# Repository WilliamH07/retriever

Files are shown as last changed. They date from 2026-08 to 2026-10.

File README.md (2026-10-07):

<div align="center">

# Retriever

**Open source autonomous outdoor mobile robot**






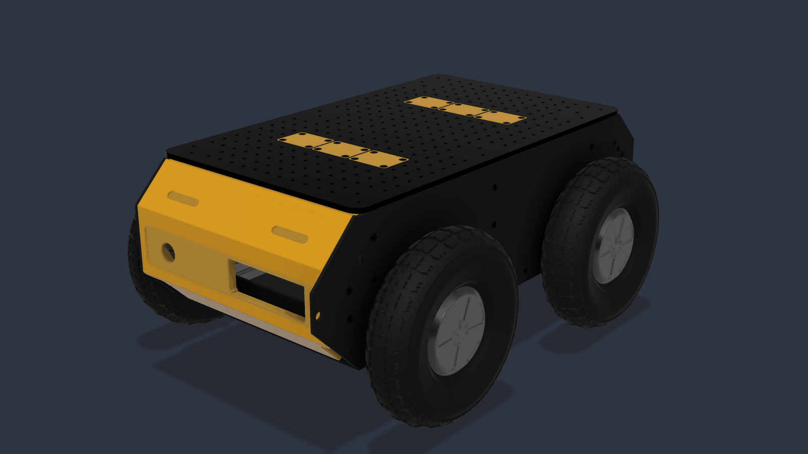
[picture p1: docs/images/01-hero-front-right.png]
Retriever


</div>

---

## What this is

Retriever is a four wheel drive outdoor mobile robot, built independently and
released as open hardware. Its single objective is autonomous outdoor
navigation using ROS 2 Jazzy and the Nav2 stack, on a chassis that anyone can
reproduce from documented, commodity parts.

The project is an open rebuild inspired by the [Clearpath
Husky](https://clearpathrobotics.com/husky-a300-unmanned-ground-vehicle-robot/),
a research platform that has become a reference in mobile robotics
laboratories. The Husky is an excellent machine and a commercial product priced
accordingly. Retriever asks a different question: how much of that capability
can be reached by one person, from recovered and off the shelf components, if
the engineering is done properly rather than cheaply?

What makes the project unusual is not the hardware, which is deliberately
ordinary. It is the discipline applied to it: a complete architecture dossier
written before the first part was cut, a documented failure mode analysis, a
hardware safety chain that no software can override, and a build plan with a
measurable exit criterion at every stage.

## Status

| Stage | Exit criterion | State |
|:-----:|---|---|
| 1 | Architecture and CAD design complete | done |
| 2 | Chassis fabricated and assembled | **current** |
| 2b | First sensor published to ROS 2 over a transport-agnostic link | **current** |
| 3 | Power chain energised, no motor connected | next |
| 4 | Motors driven, wheels raised, all stop tests pass | planned |
| 5 | Autonomous outdoor navigation to a waypoint | planned |

Beyond stage 5, the intention is to mount a [Niryo
One](https://github.com/NiryoRobotics/niryo_one) arm on Retriever and turn the
platform into a mobile manipulator.

<div align="center">
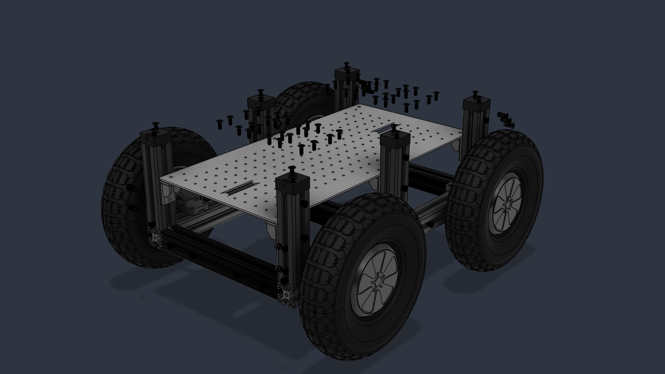
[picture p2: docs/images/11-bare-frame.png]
Aluminium extrusion frame

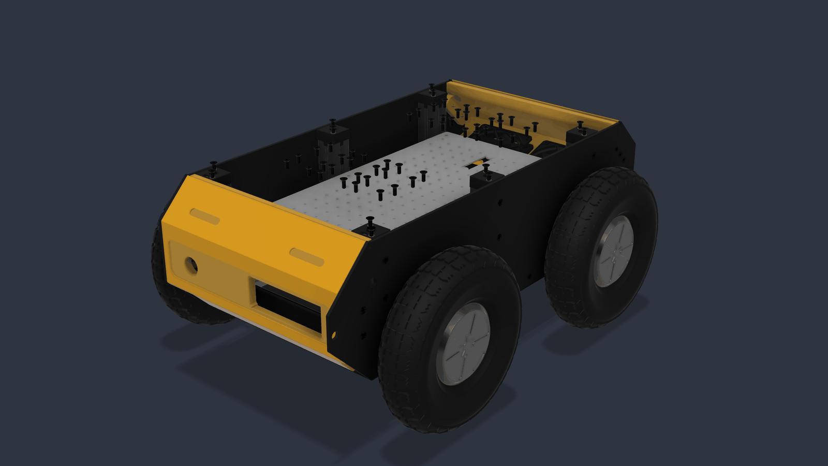
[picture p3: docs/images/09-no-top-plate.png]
Both decks visible

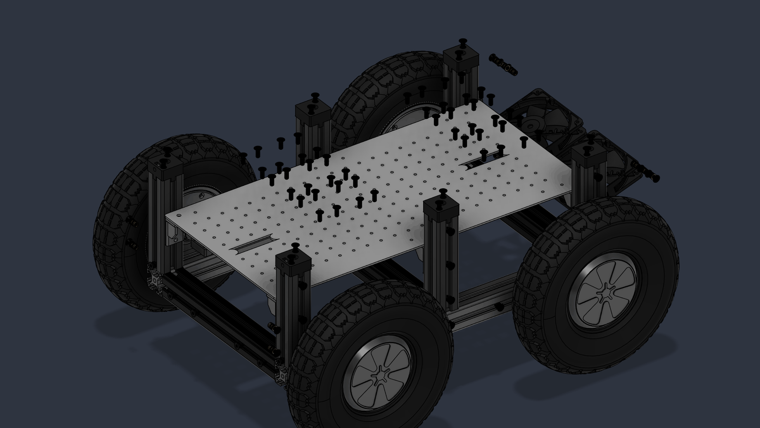
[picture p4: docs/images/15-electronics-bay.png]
Electronics bay

</div>

### The same thing, built

<div align="center">
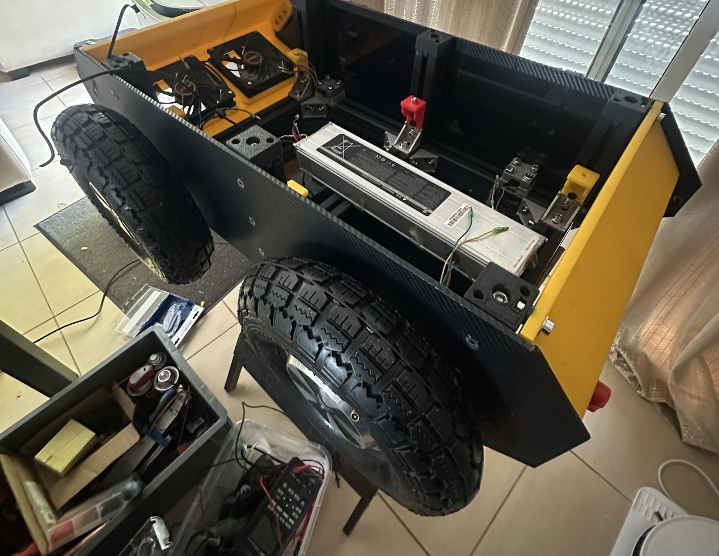
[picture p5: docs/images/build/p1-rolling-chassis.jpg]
Frame with battery and cooling fitted

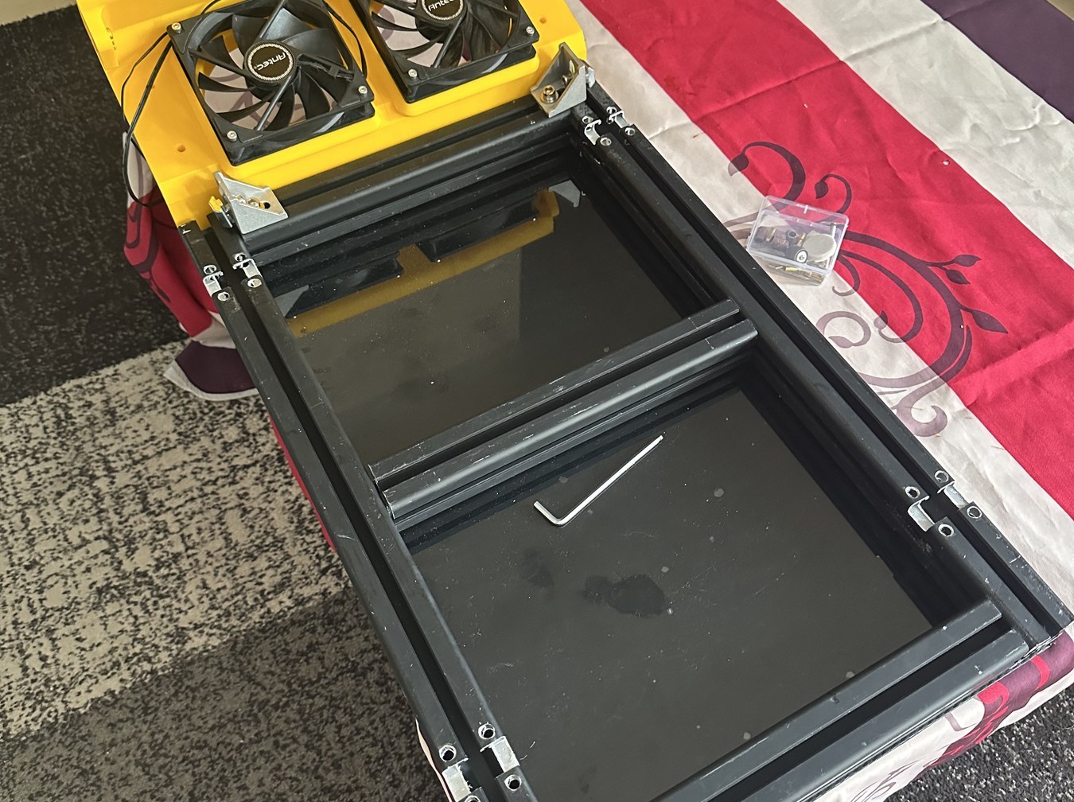
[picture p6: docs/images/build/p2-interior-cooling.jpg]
Twin fans over the electronics bay

</div>

## Three design decisions

**A CAN bus, not USB, carries every command.** Four BLDC controllers chopping
tens of amps within 30 cm of the signal wiring make USB the wrong choice for
the control path: it is a master slave bus, dynamically enumerated, with no
frame priority. CAN 2.0A at 500 kbit/s links the computer to every
microcontroller instead. USB is retained only for high bandwidth perception
sensors, whose loss degrades the mission but cannot cause dangerous motion.

**The main computer never does real time.** It runs perception, localisation,
Nav2 and the mission state machine, and it produces setpoints. A dedicated
safety microcontroller decides whether those setpoints may be executed. The
computer requests arming; the safety controller grants or refuses it. A ROS 2
bug, an out of memory kill or a blocked kernel cannot produce movement.

**Safety is hardware, and independent of software.** Six stop levels, from a
100 ms software collision monitor down to a mechanically latching emergency
stop wired in series with the main DC contactor coil. The last two levels
contain no code at all.

```
N1  ROS 2 collision monitor and cmd_vel timeout        ~100 ms
N2  ros2_control SystemInterface returns ERROR          ~50 ms
N3  ESP32 MOTION, no CAN frame for 150 ms, setpoint 0  ~150 ms
N4  ESP32 SAFETY, overcurrent or lost heartbeat         ~20 ms
N5  HARDWARE LOOP, latching emergency stop              ~10 ms
N6  Manual battery isolator and main fuse
        Only N5 and N6 are independent of all software
```

## Hardware at a glance

| | |
|---|---|
| Configuration | 4WD skid steer, outdoor |
| Structure | Aluminium extrusion frame, laser cut panels, 3D printed mounts |
| Target mass | 35 kg in running order |
| Target speed | 1.5 m/s |
| Drivetrain | 4 x 6.5 inch hub motors, 250 W each |
| Motor drivers | 4 x BLDC controllers, 36 to 48 V |
| Battery | 36 V, 280 Wh lithium ion, 10S3P |
| Endurance | 70 min at 200 W average |
| Compute | x86 SBC, Ubuntu 24.04, ROS 2 Jazzy |
| Real time | 3 x ESP32 on CAN 2.0A, 500 kbit/s |
| Localisation | GNSS, IMU and wheel odometry, dual EKF |
| Navigation | Nav2, collision monitor, twist mux |

## Repository layout

```
docs/
  architecture/     the eight document architecture dossier
  measurements/     results of the bench measurements M1 to M12
  images/           photos and renders
  sponsorship/      the sponsorship dossier
hardware/
  cad/              mechanical design, STEP and STL
  pcb/              board designs, EasyEDA sources and gerbers
  bom/              costed bill of materials
firmware/
  esp32_motion/     motor control loop, 200 Hz
  esp32_safety/     safety state machine, watchdogs, contactor
  protocol/         protocol.yaml and the code generator
ros2_ws/src/
  retriever_bringup/       launch files and system configuration
  retriever_description/   URDF, meshes, physical parameters
  retriever_msgs/          message definitions
  retriever_hardware/      ros2_control SystemInterface over SocketCAN
  retriever_control/       controller configuration
  retriever_navigation/    Nav2 and robot_localization configuration
  retriever_teleop/        manual control and the operator console
```

## Documentation

**Where the work stands:** [HANDOFF — IMU](docs/HANDOFF-banc-imu.md) and
[HANDOFF — lidar](docs/HANDOFF-banc-lidar.md) — what runs today with measured
numbers, the silent defects found and how each one worked, and what is left to
do once the sensors are mounted. In French.

**Start here:** [Démarrage](docs/DEMARRAGE.md) — what to install, how to flash
the ESP32, how to build the ROS 2 workspace, and how to verify the IMU chain at
every stage, with the traps that have already cost a day each. In French.

The architecture dossier was written before construction began. It is in
French; an English summary is planned.

| Document | Contents |
|---|---|
| [00 Index](docs/architecture/00-index-A-B.md) | Summary, assumptions, open questions |
| [01 Electrical](docs/architecture/01-inventaire-electrique.md) | Inventory, power architecture, busbars |
| [02 Comms](docs/architecture/02-comms-esp32-moteurs.md) | CAN bus, ESP32 roles, motors |
| [03 ROS 2](docs/architecture/03-ros2-etats-boot.md) | Node graph, state machine, boot |
| [04 Safety](docs/architecture/04-securite-watchdogs-capteurs.md) | Stop chain, watchdogs, sensors |
| [05 Software](docs/architecture/05-reseau-code-tests-physique.md) | Network, code layout, test strategy |
| [06 BOM](docs/architecture/06-bom-fmea-schema-plan.md) | Bill of materials, FMEA, build plan |
| [07 Operator](docs/architecture/07-interface-operateur.md) | Operator console |
| [13 Software](docs/architecture/13-architecture-logicielle-liaison.md) | Link layer, firmware, ROS 2 chain, IMU bench |

Every claim in these documents carries a marker: verified against a datasheet,
community consensus, to be measured, or an explicit assumption. Nothing gets
wired before the measurements it depends on have been made.

## Supporting the project

Retriever is self funded by a student. Three items stand between the current
platform and autonomous outdoor operation:

- **Printed circuit boards.** Three boards are being designed in EasyEDA: a
  motor driver interface, a safety and power management board, and a CAN
  distribution board.
- **Embedded AI compute.** The current x86 board runs the navigation stack, but
  not the perception outdoor autonomy asks for.
- **An outdoor LiDAR.** The blocking item. The 2D LiDAR on hand is specified for
  indoor use, and direct sunlight saturates its receiver.
- **A depth camera.** The Kinect v2 on hand is blind in daylight and its driver
  has been unmaintained since 2021.

Sponsors get a written and filmed integration tutorial for the sponsored part,
a field test video with honest performance data, attribution on the chassis and
here in this README, and private feedback on how the part behaves on a real
robot before anything is published.

The full sponsorship dossier is in [docs/sponsorship](docs/sponsorship/).
Enquiries welcome: see contact below.

## Credits

Inspired by the Clearpath Husky platform. The mechanical design was modelled
from scratch and the electrical and software architecture designed
independently. Some ROS 2 package conventions follow the open source
[husky/husky](https://github.com/husky/husky) repository, which is published
under BSD 3 Clause. Clearpath Robotics is not affiliated with this project and
does not endorse it.

See [CREDITS.md](CREDITS.md) for the full attribution.

## Licence

Software and firmware are released under the [Apache License 2.0](LICENSE).
Hardware designs, CAD and PCB files are released under the [CERN Open Hardware
Licence Version 2, Strongly Reciprocal](LICENSE-HARDWARE.txt).

## Contact

William Hanczyk, Bordeaux, France
wcontact33@gmail.com

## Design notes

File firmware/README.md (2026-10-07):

# Firmware

Three ESP32 nodes in the target architecture. The IMU bench runs on
`esp32_safety`; the motor bench now has front, rear and single-ESP profiles.
Setup and commissioning: [`esp32_motion/README.md`](esp32_motion/README.md).

| Node | Role | State |
|---|---|---|
| `esp32_safety/` | Safety state machine, current budget, watchdogs, precharge, contactor, BMS telemetry, and the BNO085 IMU. | **IMU chain only.** No safety function is implemented, and none can be validated on the serial bench. |
| `esp32_motion/` | Front/rear units, or one bench unit controlling up to four ZS-X11H drivers. | PWM/RC bench, software self-test, gated arming, watchdog and telemetry. Hall feedback and final PCB DAC/safety drivers remain to implement. |

## Layout

```
protocol/      protocol.yaml — the single source of truth — and its generator
components/    shared between every node
  retriever_protocol/   the generated header
  retriever_link/       transport-agnostic link layer
    portable/           C99, no ESP-IDF: compiled by the firmware AND by ROS 2
  retriever_imu/        BNO085 behind a four-function interface
esp32_safety/  the IMU ESP-IDF project
esp32_motion/  common front/rear/four-wheel ESP-IDF project
test/          host tests — no hardware, no ESP-IDF, no ROS
```

## The one idea worth knowing

Application code only ever sees `rt_frame_t`: an 11 bit identifier and at most
eight bytes. It does not know whether those frames travel over a CAN bus or a
USB cable. Today they travel over serial, because the CAN distribution board
does not exist yet. When it does, one Kconfig option switches the firmware and
one launch parameter switches the computer. Both CAN backends are already
written — `link_twai.c` and `socketcan_transport.cpp` — and their size is the
measure of whether the abstraction sits in the right place.

⚠️ Serial gives no arbitration, no acknowledgement, no retransmission and no
fault confinement. **No safety function is validated on it**, and stop levels
N4 and N5 stay in hardware where they belong. Section AB.5 of the architecture
document is the full list.

## Build

Full setup — toolchain, drivers, port, and how to check the result — is in
[`docs/DEMARRAGE.md`](../docs/DEMARRAGE.md). The short version:

```bash
git submodule update --init --recursive     # or tools/fetch_firmware_deps.sh
cd firmware/esp32_safety
idf.py set-target esp32
idf.py build flash
```

ESP-IDF v5.5. The SH-2 sensor hub stack is CEVA's, Apache 2.0, pinned as a
submodule and never modified; what belongs to this project is the port,
`sh2_hal_esp32_spi.c`.

## Host tests

```bash
make -C firmware/test          # protocol and framing, no hardware needed
python3 tools/check_protocol_sync.py
```

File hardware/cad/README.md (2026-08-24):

# Mechanical design

Aluminium extrusion frame, laser cut panels, 3D printed mounts. The design is
complete and the parts are made; this folder holds the files they were made
from.

```
dxf/        laser cutting profiles, one file per flat part
stl/        printable parts, ready to slice
step/       STEP exports, for anyone using a different CAD tool
source/     native CAD files
```

## Laser cut panels

Six flat parts make up the body and the decks. All are cut from sheet, and all
are in `dxf/`.

| File | Part | Material |
|---|---|---|
| `ETG_Plateau_superieur_PMMA_3mm.dxf` | Upper deck | PMMA, 3 mm |
| `Plancher.dxf` | Floor of the payload bay | |
| `Panneau_AVANT.dxf` | Front panel | |
| `Panneau_ARRIERE.dxf` | Rear panel | |
| `Panneau_lateral_DROIT.dxf` | Right side panel and wheel arch | |
| `Panneau_lateral_GAUCHE.dxf` | Left side panel and wheel arch | |

The side panels carry the wheel arches, so their outline is what sets the
wheelbase and the track. Change one and the URDF in
[`ros2_ws/src/retriever_description`](../../ros2_ws/src/retriever_description)
has to follow.

Material and thickness are recorded in the file name where they matter. Fill in
the blanks in the table above as each part is confirmed.

## Printed parts

The corner brackets, the deck brackets, the wheel mounts, the fan housing and
the front section are printed. STL files go in `stl/`.

For each part, note here the material, the layer height, the wall count and
the infill actually used, not the ones intended. A printed bracket that holds a
35 kg machine is a structural part, and the print settings are part of the
specification.

## Frame

The frame is aluminium extrusion, cut and drilled by hand. Lengths and the
drilling pattern belong in `source/`, with the extrusion profile and the corner
connector reference recorded here once confirmed.

## Renders

The renders in [`docs/images`](../../docs/images) are produced from this model
by a Fusion 360 script that fixes the camera, the visual style and the
visibility of each assembly group. A regenerated set is directly comparable to
the current one.

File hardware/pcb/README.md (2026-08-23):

# Printed circuit boards

Three boards, currently being designed in EasyEDA.

| Board | Function | State |
|---|---|---|
| [`motor_interface/`](motor_interface/) | Hall passthrough with wire colour remapping, level shifting and signal conditioning to the pulse counters, CAN breakout | routed, pre production review |
| [`safety_power/`](safety_power/) | Power distribution, 37 V / 12 V / 5 V buses, fusing, overvoltage and regeneration protection, precharge, current sensing | specified |
| `can_distribution/` | CAN bus distribution with termination, node breakout and supply fan out | in design |

Each board folder should end up containing:

```
schematic.pdf        human readable schematic
gerbers/             fabrication output
bom.csv              bill of materials
pick_and_place.csv   if assembled
README.md            what it does, connectors, test points
```

Source files are exported from EasyEDA. Fabrication output is committed so that
anyone can order the boards without opening a design tool.

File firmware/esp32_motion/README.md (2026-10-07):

# MOTION — banc avant, arrière ou quatre roues

Un même projet ESP-IDF v5.5 produit les programmes des deux ESP32 classiques
DevKitC/WROOM et celui du banc à un seul ESP32. Les variateurs ZS-X11H assurent
la commutation BLDC ; l'ESP32 leur fournit VR, DIR et STOP. Le firmware ne
commute pas directement les phases du moteur.

Les cartes `motor_interface` étant encore en conception, ces profils pilotent
**le montage de banc PWM + RC**. Ils ne pilotent pas encore le MCP4728, les
Hall, l'ADS1115, `/SAFE`, le frein EL ou le watchdog externe de la carte finale.

## Profils et câblage

| Profil | Identité | Roues globales | Sorties locales | Masque pour armer |
|---|---|---|---|---|
| `front` | MOTION_FRONT, 2 | m0 avant gauche, m1 avant droite | 0, 1 | 3 |
| `rear` | MOTION_REAR, 3 | m2 arrière gauche, m3 arrière droite | 0, 1 | 12 |
| `bench4`, 3 moteurs | MOTION_FRONT, 2 | m0, m1, m2 | 0, 1, 2 | 7 |
| `bench4`, 4 moteurs | MOTION_FRONT, 2 | m0, m1, m2, m3 | 0, 1, 2, 3 | 15 |

Le banc utilise l'identité FRONT : ne pas connecter simultanément un banc4 et
un FRONT sur le même CAN. Les cartes avant et arrière utilisent les **mêmes
broches locales**, mais sélectionnent des indices de roues différents.

| Sortie locale | PWM → VR | DIR | STOP |
|---|---|---|---|
| 0 | GPIO25 | GPIO26 | GPIO27 |
| 1 | GPIO32 | GPIO33 | GPIO14 |
| 2, banc seulement | GPIO18 | GPIO19 | GPIO21 |
| 3, banc seulement | GPIO22 | GPIO23 | GPIO13 |

UART USB : GPIO1/3, 921600 bauds. CAN : TX GPIO5, RX GPIO4, 500 kbit/s,
transceiver externe obligatoire. Deux terminaisons de 120 Ω aux extrémités.
GPIO5 est une broche de strapping : vérifier son état haut au démarrage.

**Interface DIR/STOP obligatoire.** Le drain ouvert interne ne rend pas les
GPIO tolérants au 5 V. Le rappel du variateur ne doit jamais arriver directement
sur l'ESP32. Voir les limites électriques de la
[datasheet Espressif](https://documentation.espressif.com/esp32_datasheet_en.html).

Deux configurations logicielles sont prévues ; choisir celle qui correspond au
montage effectivement réalisé et mesurer les niveaux avant connexion :

- Par défaut, interface externe **non inversante**, côté ESP limité à 3,3 V,
  GPIO en drain ouvert. STOP logique 0 doit donner STOP variateur bas.
- `--inverted` : un NMOS externe par ligne, source à GND, drain à DIR ou STOP,
  grille au GPIO. Le GPIO est en push-pull 3,3 V ; niveau GPIO haut donne
  niveau variateur bas. Tirer la grille du NMOS STOP à 3,3 V par 10 kΩ pour
  maintenir STOP bas pendant le reset tant que ce rail est alimenté.

Le RC de banc est GPIO PWM → 1 kΩ → VR, avec 2,2 µF vers GND sur VR et un
rappel 10 kΩ vers GND **côté variateur**. Pleine échelle électrique environ
3 V, à vérifier sous charge ; elle ne représente pas une vitesse étalonnée.
Les masses de l'ESP et des interfaces sont communes. EL n'est pas piloté.
Le comportement en absence d'alimentation logique reste à vérifier matériellement.

## Compiler et téléverser

Sur le Mac, ESP-IDF v5.5 est installé dans `~/esp/esp-idf-v5.5`. Le raccourci
`get_idf`, disponible dans un nouveau terminal, active son environnement.
Installation selon la [notice officielle Espressif](https://docs.espressif.com/projects/esp-idf/en/v5.5/esp32/get-started/linux-macos-setup.html).
Le script Mac l'active automatiquement ; depuis la racine du dépôt :

```bash
./tools/flash_motion_mac.sh bench4 --count 4
./tools/flash_motion_mac.sh bench4 --count 4 --flash --port <port-USB>
```

La première commande compile seulement ; la seconde téléverse. `--count`
configure les premiers emplacements ; il ne détecte pas les roues présentes.
Les profils `front`,
`rear`, `--inverted` et `--transport can` fonctionnent aussi avec ce raccourci.

Depuis la racine du dépôt, après chargement de l'environnement ESP-IDF :

```bash
. <installation-esp-idf-v5.5>/export.sh
python3 tools/flash_motion.py front
python3 tools/flash_motion.py rear
python3 tools/flash_motion.py bench4 --count 3
```

Chaque profil, transport, nombre de sorties et type d'interface a son propre
répertoire sous `firmware/esp32_motion/build/`. Le programme régénère son
`sdkconfig` depuis les valeurs versionnées à chaque exécution : pas de rôle
avant conservé par erreur dans une compilation arrière, ni d'ancien défaut
masquant une modification du watchdog. Pour modifier un réglage permanent,
modifier les defaults versionnés ; les changements manuels de ce `sdkconfig`
généré sont écrasés.

Identifier physiquement les deux ports avant de flasher, puis :

```bash
python3 tools/flash_motion.py front --flash --port <port-ESP-avant>
python3 tools/flash_motion.py rear --flash --port <port-ESP-arriere>
```

Ajouter `--inverted` pour les NMOS externes inversants. Ajouter `--transport can`
quand les transceivers sont câblés. Pour une seule roue sur un essieu, utiliser
`--count 1` : elle occupe le **premier** emplacement local (m0 ou m2). Pour
une roue droite seule, déplacer provisoirement son câblage sur cet emplacement
et consigner l'écart dans le relevé du banc.

Avec l'avant droit déconnecté, conserver `--count 4` et les indices fixes.
Les roues présentes sont m0, m2, m3 : masque 13 (1 + 4 + 8). Pour les premiers
essais, autoriser séparément 1, 4 et 8 ; garder m1 à zéro. `--count 3` serait
adapté à un câblage regroupé sur les sorties 0, 1, 2, qui est un autre montage.
Après remontage de la quatrième roue : masque 15.

**Protocole 0.2.0.** Reconstruire le workspace ROS et reflasher le nœud IMU
quand il est utilisé avec ce workspace : le hash est commun à tout le dépôt.
Les captures anciennes restent décodables, mais l'ancien outil de commande
ne valide pas MOTOR_SESSION et ne peut plus armer ce firmware.

## Self-test et diagnostics

Le firmware initialise toutes les sorties à l'arrêt et interdit les moteurs.
Avant cette initialisation, pendant le reset, leur état dépend des rappels et
de l'interface électrique du banc.

| Bit | Contrôle réellement effectué |
|---|---|
| CONFIG, 0x01 | Indices, GPIO valides et distincts, réservations flash/console/CAN, limites finies |
| GPIO, 0x02 | Configuration DIR/STOP, écriture puis lecture des niveaux GPIO de repos |
| PWM, 0x04 | Initialisation LEDC, fréquence 20 kHz et lecture de chaque duty à zéro |
| TASK, 0x08 | Création de la tâche 200 Hz et inscription au task watchdog ESP-IDF |
| LINK, 0x10 | Initialisation du transport, files et tâches de liaison |

Attendu : `passed=31` (0x1F), `failed=0`, `output_errors=0`. Un défaut de
périphérique inhibe l'armement jusqu'au redémarrage. Le watchdog de tâche est
réglé à 2 s avec panic/reset ; il ne remplace pas le watchdog matériel externe.

Ces contrôles vérifient les périphériques et le logiciel. Ils ne prouvent pas
la tension VR au connecteur, la présence du variateur, le mouvement, le sens
mécanique ou le freinage. `configured_mask` décrit la configuration compilée,
**pas une détection automatique de la roue manquante**. Les contrôles physiques
restent dans la recette ci-dessous.

Les états, diagnostics et heartbeats sont publiés à 10 Hz :

| | Avant ou banc4 | Arrière |
|---|---|---|
| Consignes appliquées | MOTOR_STATE, 0x1A0 | MOTOR_STATE_REAR, 0x1A1 |
| Self-test / compteurs | MOTOR_DIAG_FRONT, 0x1A2 | MOTOR_DIAG_REAR, 0x1A3 |
| État / uptime / hash | HEARTBEAT_MOTION_FRONT, 0x702 | HEARTBEAT_MOTION_REAR, 0x703 |

Les quatre valeurs sont toujours ordonnées m0, m1, m2, m3. Les positions non
locales restent nulles. L'état renvoie une consigne électrique après limites,
pente et autorisations ; **il ne renvoie aucune vitesse mesurée**. Les erreurs
de sortie rendent cette consigne non fiable : lire `OUTPUT_FAULT` et le compteur.

READY signifie logiciel initialisé, sorties interdites. ACTIVE signifie
armement accepté, y compris à consigne zéro. DEGRADED signale un arrêt logiciel
ou une perte de commandes après armement. FAULT signale un self-test ou une
sortie en échec. `PROTOCOL_BLOCKED` précise qu'aucune session concordante n'a
encore été reçue, même si les périphériques sont prêts.

Sur CAN, les journaux restent sur la console locale : le LOG commun du banc
série n'est pas utilisé par deux émetteurs concurrents. Les diagnostics gardent
leurs identifiants distincts. LINK_PONG est une réponse à une cible explicite.

## Armement et comportement en défaut

L'ordinateur valide le hash reçu puis envoie MOTOR_SESSION avec l'identité
cible et le même hash. Le firmware vérifie aussi ce hash. Ensuite :

1. Envoyer une MOTOR_CMD à zéro, répétée à 50 Hz.
2. Attendre une télémétrie fraîche avec sorties nulles et self-test réussi.
3. Envoyer MOTOR_ENABLE avec magic 0xEB et le masque voulu.
4. Attendre le masque confirmé, puis envoyer les consignes à 50 Hz.

Le firmware rejette les DLC incorrects, les gardes incorrectes, les masques
hors b0..b3 et les consignes hors [-1,1]. Une commande invalide ne rafraîchit
pas le watchdog. Les roues de l'autre essieu sont filtrées.

Défauts et réglages du banc :

- Plus de 500 ms sans commande valide : consignes nulles, STOP bas et
  **désarmement mémorisé**. Le retour de liaison ne réarme jamais.
- Arrêt logiciel : consignes nulles et désarmement, réarmement explicite à zéro.
- Défaut de sortie : tentative de STOP/PWM zéro sur toutes les sorties,
  défaut mémorisé, redémarrage requis.
- Bus-off observé : arrêt logiciel mémorisé, même après reprise automatique du CAN.
- Limite de duty par défaut : 0,25. Une demande supérieure est limitée et
  `LIMITED` est publié. Ce n'est ni 25 % d'une vitesse mesurée ni une limite de courant.
- Accélération : 2 unités/s. Réduction et coupure sans rampe logicielle ; le RC
  et la mécanique ont leur propre délai.
- Inversion : passage à zéro, DIR conservé et pause de 250 ms avant inversion.
  **Cette pause ne démontre pas que la roue est arrêtée.** Sans Hall, attendre
  l'immobilisation mécanique avant de demander l'autre sens.

Le traitement logiciel se fait au prochain cycle de 5 ms sous ordonnancement
normal. STOP donne la roue libre, pas un freinage garanti. Les essais se font
roues levées, avec une coupure de puissance accessible. La chaîne matérielle
`/SAFE` / EL / contacteur reste à réaliser et à valider sur les cartes.

## Vérifier sans ROS

Dépendances : `pyyaml`, `pyserial` ; pour SocketCAN sous Linux, `python-can`.

```bash
python3 tools/motor_bench.py --device <port-avant> --self-test --report <resultat-avant.json>
python3 tools/motor_bench.py --device <port-arriere> --node rear --self-test --report <resultat-arriere.json>
```

`--self-test` observe sans envoyer de commande ou d'armement et retourne un
code non nul si la télémétrie est absente, périmée, incohérente, en erreur ou
si les sorties sont actives. Par défaut, l'outil **ne demande plus de reset**
à l'ouverture USB (`--no-reset` reste accepté). `--reset` demande explicitement
un redémarrage : l'utiliser uniquement puissance moteur coupée. Le circuit
USB-série et son pilote peuvent encore produire des transitions à l'ouverture ;
les rappels matériels restent nécessaires pendant un reset ou une coupure USB.

L'acquisition de la télémétrie est limitée à trois secondes, puis l'outil
observe pendant la durée `--seconds`. Les octets du bootloader, émis à une
autre vitesse sur UART0, restent visibles dans `decoder_acquisition`.
`decoder_observation` compte la période synchronisée : toute erreur de CRC,
format ou débordement pendant cette période fait échouer le test. Le verdict
global est `exit_code: 0`, pas seulement `healthy: true`.

`healthy` décrit la fraîcheur de la télémétrie et le self-test. Il ne signifie
pas que l'armement est autorisé. `session_ready` exige en plus la confirmation
de MOTOR_SESSION et d'une commande fraîche dans les deux retours STATE et
DIAG. Avant l'armement, le script répète uniquement SESSION et les commandes
zéro jusqu'à cette confirmation. Les premiers paquets perdus pendant le boot
ne doivent pas conduire à une tentative d'armement prématurée. Le firmware
attend aussi l'installation du traitement des commandes avant sa première
publication d'état.

Sur le Mac, avant ROS, depuis la racine du dépôt :

```bash
source ~/esp/esp-idf-v5.5/export.sh
python3 tools/motor_bench.py --device /dev/cu.usbserial-0001 --self-test --seconds 10 --report firmware/esp32_motion/build/mac-self-test.json
python3 tools/motor_bench.py --device /dev/cu.usbserial-0001 --enable 0 --duty 0 0 0 0 --seconds 3 --report firmware/esp32_motion/build/mac-zero-test.json
```

Remplacer le port si nécessaire. La seconde commande vérifie les commandes
zéro et le retour de désarmement sans autoriser une roue. Attendre
`exit_code: 0` et `shutdown_confirmed: true`. Ensuite seulement, roues levées
et interface électrique vérifiée, essayer une roue à la fois :

```bash
python3 tools/motor_bench.py --device /dev/cu.usbserial-0001 --enable 1 --duty .1 0 0 0 --seconds 3
python3 tools/motor_bench.py --device /dev/cu.usbserial-0001 --enable 4 --duty 0 0 .1 0 --seconds 3
python3 tools/motor_bench.py --device /dev/cu.usbserial-0001 --enable 8 --duty 0 0 0 .1 --seconds 3
```

Ces trois essais laissent l'avant droit (m1) interdit. Vérifier le mouvement
physique, le sens et l'arrêt ; les retours actuels ne mesurent pas la rotation.

### Diagnostic de sélection des sorties

Les quatre canaux LEDC sont indépendants et partagent uniquement le timer
de fréquence. Une seule tâche effectue les écritures. À chaque cycle de 5 ms,
le firmware relit les rapports cycliques LEDC du cycle précédent et les pads
STOP. Un écart avec les écritures attendues déclenche un défaut mémorisé et
l'arrêt de toutes les sorties. Les sorties inactives sont réécrites à zéro
avant la mise à jour des sorties actives.

`applied_m0..m3` est maintenant calculé depuis les registres PWM relus, avec
le signe de la commande écrite. Ce retour peut avoir un cycle de retard et
ne vérifie ni la tension VR après l'interface, ni la rotation. Le masque
`stop_gpio_high` est celui des niveaux physiques côté ESP, avant l'interface ;
sa polarité dépend donc de `--inverted`.

Après téléversement de cette version, exemple de relevé pour m3 seul :

```bash
python3 tools/motor_bench.py --device /dev/cu.usbserial-0001 --enable 8 --duty 0 0 0 .1 --seconds 3 --logs --report firmware/esp32_motion/build/m3-diagnostic.json
```

Le journal doit contenir `readback pwm=[0,0,0,102]` au plateau (PWM sur 1023).
Pour l'interface non inversante, `stop_gpio_high=0x08` est attendu ; pour les
NMOS inversants, `0x07`. Les GPIO STOP d'une interface non inversante doivent
avoir un rappel externe côté 3,3 V pour pouvoir être relus au niveau haut.
Un arrêt pour `readback ... stop=0/1` peut révéler ce rappel absent.
Le script interrompt aussi l'essai si les retours signalent une roue non
commandée active ou un sens contraire. Le rapport conserve les pics observés
dans `peak_applied` et les derniers journaux dans `esp_logs`, même après l'arrêt.

Ces contrôles améliorent le diagnostic ; ils ne prouvent pas la cause des
mouvements inattendus observés sur le banc. Le test hôte `test_motor_outputs`
exécute le code de sortie réel avec GPIO/LEDC simulés, y compris des erreurs
de lecture et d'écriture. La validation électrique et mécanique reste à faire.

Mouvement bref d'une seule roue, 0,10 de consigne, trois secondes :

```bash
python3 tools/motor_bench.py --device <port-avant> --enable 1 --duty .1 0 0 0
python3 tools/motor_bench.py --device <port-arriere> --node rear --enable 4 --duty 0 0 .1 0
python3 tools/motor_bench.py --device <port-banc4> --enable 1 --duty .1 0 0 0
```

L'outil attend la validation et l'acquittement de l'armement avant de demander
le mouvement. À la sortie, il tente trois désarmements et commandes zéro. Le champ
`shutdown_confirmed` indique si une télémétrie fraîche a confirmé le
désarmement à zéro. Si le câble est coupé, le timeout firmware prend le relais ; l'outil ne prétend
pas avoir confirmé un arrêt sur une liaison perdue.

CAN après configuration de `can0` à 500 kbit/s :

```bash
python3 tools/motor_bench.py --transport can --interface can0 --node rear --self-test
```

**Un seul producteur de commandes sur le bus.** MOTOR_CMD et MOTOR_ENABLE
portent les quatre roues et sont diffusés : ne pas lancer deux outils de
commande sur le même CAN. Le script est un outil de recette d'un nœud à la
fois ; il ne constitue pas encore un superviseur ROS unique des deux essieux.

## ROS et Foxglove

### Préparer l'ordinateur de contrôle

L'archive locale `firmware/esp32_motion/build/transfer/retriever-motor-bench-source.tar.gz`
contient les sources actuelles, y compris les modifications non commitées,
sans ESP-IDF ni fichiers de compilation. La copier sur le calculateur Ubuntu
équipé de ROS 2 Jazzy, puis l'extraire dans un dossier dédié :

```bash
mkdir -p ~/retriever-motor-bench
tar -xzf <chemin-archive> -C ~/retriever-motor-bench
cd ~/retriever-motor-bench/ros2_ws
source /opt/ros/jazzy/setup.bash
rosdep install --from-paths src --ignore-src -y
colcon build --symlink-install --packages-up-to retriever_bringup
cd ..
```

`rosdep` doit être initialisé sur le calculateur. Pour ouvrir la liaison avec
un ESP qui pilote les quatre roues, utiliser son port USB persistant :

```bash
./tools/run_motor_bench_ros.sh bench4 /dev/serial/by-id/<identifiant-ESP>
```

Pour deux ESP sur deux ports USB :

```bash
./tools/run_motor_bench_ros.sh axles <port-avant> <port-arriere>
```

Les profils `front` et `rear` lancent un seul essieu. Ce raccourci charge ROS
et le workspace, puis ouvre la liaison et les diagnostics sans armer les
moteurs. Ajouter `foxglove:=false` pour lancer sans affichage Foxglove.
Les essais de mouvement et leur relevé viennent après la recette électrique.

### Commandes et retours

Le pont accepte `link.peer: motion_front` et `link.peer: motion_rear`. Il envoie
MOTOR_SESSION, décode les retours de son essieu et publie
`retriever/motor_state` (avec `node_id`) et `retriever/motor_diagnostics`.
Le panneau Diagnostics reprend le self-test, l'âge et les compteurs.

```bash
ros2 launch retriever_bringup bench_motors.launch.py device:=<port-avant>
ros2 launch retriever_bringup bench_motors.launch.py device:=<port-arriere> peer:=motion_rear
```

Ces commandes alternatives testent **un essieu à la fois**. Pour deux ESP en
USB simultanés, la launch `bench_axles.launch.py` sépare leurs retours tout en
leur fournissant une commande commune. Le banc4 garde le layout Foxglove
existant. Exemple pour les deux ports :

```bash
ros2 launch retriever_bringup bench_axles.launch.py front_device:=<port-avant> rear_device:=<port-arriere>
```

Les commandes restent `/retriever/motor_command`, `/retriever/motor_enable` et
`/retriever/estop`. Les retours sont `/retriever/front/motor_state` et
`/retriever/rear/motor_state`, avec les diagnostics dans les mêmes préfixes.
Publier la commande à 50 Hz : cette launch coupe la consigne ROS après 0,5 s
sans message. Pour armer les deux essieux, publier des zéros, puis masque 15.

Le pilotage CAN simultané des deux essieux par un superviseur unique
et le contrôle fermé avec Hall restent une étape suivante.

## Recette physique à relever

Consigner le port, le profil, le hash, le câblage, le sens mécanique, les niveaux
mesurés et le résultat pour chaque essai. Aucun de ces résultats n'est acquis
par la seule compilation.

1. Sans puissance moteur : GPIO côté ESP ≤3,3 V, STOP côté variateur bas au
   démarrage/reset, VR zéro. Vérifier la polarité de l'interface DIR/STOP.
2. Self-test sur chaque ESP : bits 0x1F, aucun échec, hash concordant ; masque
   3 pour l'avant, 12 pour l'arrière, ou 7 pour le banc à trois roues.
3. Roues levées, tester une roue à la fois à 0,10 : bon moteur, bon sens,
   tension VR cohérente. Le sens peut dépendre du câblage moteur ; consigner
   les inversions nécessaires avant utilisation d'une commande de déplacement.
4. Arrêt explicite : mesurer STOP bas et VR qui revient à zéro. Vérifier les
   autres roues et mesurer le délai électrique, puis la décélération réelle.
5. Couper le flux de commandes ou débrancher l'USB : après 500 ms plus un
   cycle de contrôle, STOP bas. Reconnecter **sans reset**, envoyer une nouvelle
   consigne et vérifier l'absence de redémarrage. Zéro puis réarmement requis.
6. Tester reset, absence de variateur et quatrième roue non câblée : le
   self-test logiciel ne doit pas être interprété comme une présence physique.
7. Après câblage CAN : identifier les deux nœuds, vérifier les retours distincts,
   puis perte de bus / reprise sans réarmement. Ne pas simuler un défaut en
   court-circuitant un GPIO ni en appliquant 5 V à l'ESP.
8. Endurance dix minutes : états/diagnostics/heartbeats à environ 10 Hz,
   compteurs de rejet, liaison et sortie stables ; conserver le relevé JSON
   ou l'enregistrement ROS. La vitesse réelle demande un retour Hall.

## Vérifications automatisées

```bash
make -C firmware/test
python3 tools/check_protocol_sync.py
python3 -m unittest discover -s tools/tests
```

Le même moteur de règles C est compilé dans le firmware et dans les tests
hôte. Les tests couvrent armement à zéro, validation du hash, mapping des
essieux, perte de consigne entre deux cycles, absence de reprise automatique,
limite, rampe, inversion, arrêt et données invalides. La CI compile les profils
avant, arrière et banc sur les transports série et CAN.

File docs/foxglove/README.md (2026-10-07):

# Mises en page Foxglove

Versionnées ici pour une raison simple : une mise en page Foxglove vit dans le
stockage local de l'application, elle n'est ni partagée entre machines ni
sauvegardée, et **sa suppression est définitive** — il n'y a pas d'annulation.
Reconstruire six panneaux à la main après chaque mise à jour, changement de
poste ou fausse manœuvre est exactement le genre de travail qu'un fichier
versionné supprime.

## `bench_imu.json` — banc B1

Les six panneaux de la recette de banc :

| Panneau | Contenu |
|---|---|
| 3D | repère fixe `imu_world`, le marqueur suit `imu_link` |
| Plot | `/imu/data.angular_velocity` sur les trois axes |
| Plot | `/imu/data.linear_acceleration` sur les trois axes, **gravité comprise** |
| Diagnostics | les trois vérifications du pont : capteur, liaison, nœud |
| Raw Messages | `/retriever/imu_status` — qualités et état d'étalonnage |
| Raw Messages | `/retriever/link_status` — hash du protocole, erreurs, aller-retour |

### Importer

Dans Foxglove Studio, menu des mises en page (l'icône à deux rectangles, en
haut à droite) → **Import from file…** → choisir ce fichier.

Se connecter ensuite à `ws://<adresse-du-calculateur>:8765`.

⚠️ Le panneau 3D n'affiche quelque chose que si `bench.publish_tf` est actif
dans `ros2_ws/src/retriever_bringup/config/link_bench.yaml`. C'est une aide de
banc : sur le robot, c'est l'EKF qui publie cette transformation, et laisser les
deux actifs donnerait deux sources sur la même arête de l'arbre TF.

## `bench_lidar.json` — banc lidar

| Panneau | Contenu |
|---|---|
| 3D | `/scan` coloré par la distance, repère fixe `base_link`, grille de 20 m |
| Plot | trois rayons du scan, pour voir la stabilité des mesures dans le temps |
| Raw Messages | `/scan` — `angle_min`, `angle_increment`, `range_min/max`, la taille du tableau |
| Diagnostics | `/diagnostics` |

Vue **orthographique vue de dessus** : c'est la seule qui permette de juger
qu'une pièce ressemble à une pièce. En perspective, un scan 2D est illisible.

⚠️ Deux ponts Foxglove ne peuvent pas écouter le même port. Si le banc IMU
tourne déjà, lancer le lidar avec `foxglove:=false`.

### Ce qu'on regarde, et dans quel ordre

1. **Diagnostics** — les trois lignes au vert. C'est le seul panneau qui dit
   « tout va bien » sans qu'on ait à interpréter des chiffres.
2. **3D** — on bouge le capteur, le repère suit. Vérifie la chaîne entière
   d'un coup d'œil, y compris les conventions de repère.
3. **Plots** — au repos, `linear_acceleration` doit avoir une norme de
   9,81 m/s². Un écart constant dans toutes les orientations est une erreur
   d'échelle ; un écart qui varie avec l'orientation est un biais, et c'est ce
   que corrige l'étalonnage (`tools/imu_cal.py`, voir `docs/DEMARRAGE.md` §4 bis).
4. **`/retriever/link_status`** — `protocol_match` vrai, `unknown_frames` à 0.

*Copyright (c) 2026 William Hanczyk — Apache License 2.0*

## `bench_motors.json` — banc B2, les variateurs

| Panneau | Contenu |
|---|---|
| Publish ×2 | `/retriever/motor_enable` — **ARMER** (masque 7 = m0..m2, 15 = les quatre) et **DESARMER** (0) |
| Publish | `/retriever/motor_command` — la consigne, `duty: [m0, m1, m2, m3]` dans [-1, 1] |
| Publish ×2 | **STOP** (zéros) et **ARRÊT D'URGENCE** (`/retriever/estop`, à ré-armer ensuite) |
| Plot | `/retriever/motor_state.applied[0..3]` — ce que le nœud applique vraiment, après pente et chien de garde |
| Plot | `/retriever/motor_state.cmd_age_ms` — doit rester sous 30 ms tant que le pont tourne |
| Diagnostics | Moteurs / Liaison / Nœud MOTION_FRONT |
| Raw Messages | `/retriever/motor_state` et `/retriever/motion/node_status` |

Séquence : **ARMER** → éditer `duty` dans le panneau consigne → **ENVOYER** →
la roue tourne 10 s (`motors.command_timeout_s`) puis s'arrête seule, ou avant
avec **STOP**. Modifier `duty` ne publie rien tant qu'on n'a pas cliqué.

⚠️ Le panneau Publish n'émet qu'au clic. C'est le pont qui répète la dernière
consigne à 50 Hz vers l'ESP32 ; c'est lui aussi qui l'annule après
`command_timeout_s`. Le chien de garde du firmware (500 ms sans trame) reste
la vraie protection si le PC ou le câble lâche.

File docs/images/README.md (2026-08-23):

# Images

CAD renders of the current assembly, captured from the Fusion 360 viewport by
script. All 1600 x 900, web sized, so the repository stays quick to clone.

## Overall

| File | Content |
|---|---|
| `01-hero-front-right.png` | Three quarter view, front right. README banner |
| `02-hero-rear-left.png` | Three quarter view, rear left |
| `03-low-angle.png` | Low angle, near ground level |
| `04-high-angle.png` | High angle |
| `00-preview.png` | Same as 01, lighter, for embeds |

## Orthographic, for dimensioning

| File | Content |
|---|---|
| `05-front.png` | Front elevation |
| `06-side-right.png` | Right side elevation |
| `07-top.png` | Plan view, front pointing up |
| `08-rear.png` | Rear elevation |

## Internal architecture

| File | Content |
|---|---|
| `09-no-top-plate.png` | Top plate hidden, both decks visible |
| `10-upper-deck.png` | The 3 mm upper deck and its six brackets |
| `11-bare-frame.png` | Aluminium extrusion frame alone |
| `15-electronics-bay.png` | Interior, low voltage side |
| `16-lower-deck-37v.png` | Lower floor, the 37 V compartment |

## Details

| File | Content |
|---|---|
| `12-wheel-mount.png` | Hub motor axle mount |
| `13-deck-bracket.png` | Printed deck bracket in the extrusion slot |
| `14-front-panel.png` | Front panel |

## Regenerating

The renders are produced by a Fusion 360 script that sets the camera, the
visual style and the visibility of each assembly group, then writes the PNGs.
Joints and sketches are hidden first, otherwise their cyan arcs appear over the
wheels. Framing is fixed, so a regenerated set is directly comparable to this
one.

Full resolution originals, 2560 x 1440 for the overall views, are kept outside
the repository.

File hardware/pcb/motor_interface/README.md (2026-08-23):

# Motor interface board

Sits between the four hub motors and the motor controllers, on the Hall sensor
cables. It does two independent jobs at once.

**It changes the wire colour code.** The motor loom and the controller loom do
not agree on two of the five conductors. Rather than a taped adapter that
nobody can read six months later, the board carries the mapping in silkscreen
next to every pad. You follow the printed colour; you do not think.

**It taps the twelve Hall signals for an ESP32**, which counts transitions and
publishes wheel odometry. The tap is a spy, never an intermediary.

> **Hard requirement.** If the ESP32 is removed, unpowered or faulty, the motor
> to controller link must keep working. Nothing in the tap sits in series with
> the passthrough, which stays a purely metallic path.

## Colour mapping

| Signal | Motor side | Controller side |
|---|---|---|
| GND | black | black |
| +5 V | red | red |
| Hall A | yellow | yellow |
| Hall B | **blue** | **white** |
| Hall C | **green** | **orange** |

Only two conductors change. Those two are the whole reason the board exists,
and they are the two someone will get wrong, so they are boxed on the
silkscreen.

## Level shifting

Hall outputs are open collector and the pull up lives in the motor controller,
tied to +5 V. The line therefore swings to 5 V, and ESP32 GPIOs are not 5 V
tolerant. Each tap follows this chain and no other:

```
Hall net (0/5 V) ──[ 1 kR ]──┬──[ 10 nF ]── GND
                             └──> Schmitt buffer ──> GPIO (0/3.3 V)
```

- Buffer: 2 x `SN74LVC14AD`, powered from 3.3 V, inputs 5.5 V tolerant. It is
  an inverter, so the state read by software is the complement of the sensor.
- RC: 1 kR + 10 nF, 10 us, corner near 16 kHz. The useful signal peaks at
  **110 Hz**; the noise to reject is the 16 to 20 kHz power PWM coupled from
  the phase wires. Do not change one value without recomputing the other.
- Buffer input current is a few microamps, so the load seen by the Hall sensor
  is negligible and the passthrough survives the loss of 3.3 V.

## On board

| Block | Detail |
|---|---|
| Passthrough | 8 x 5 way connectors, pin *n* to pin *n*, straight traces |
| Tap | 12 x RC, 2 x SN74LVC14AD |
| ESP32 | DevKitC 38 pin on two 1x19 sockets, 22.86 mm row pitch |
| CAN | `SN65HVD230D`, 3.3 V native, 120 R termination behind a jumper, two parallel 3 pin connectors so the bus passes through without a stub |
| 5 V input | screw terminal, 500 mA PPTC, `SMAJ5.0A` TVS, `SS14` series Schottky, isolation jumper |
| Indicators | 12 activity LEDs, one per Hall channel, driven from the buffer outputs; 2 presence LEDs for 3.3 V and the motor 5 V rail |

## The USB and converter conflict

On a DevKitC the `5V` pin is wired straight to USB VBUS with no diode. Two 5 V
sources in parallel means the higher one back feeds the other, which would push
current into the host computer's USB port.

The series `SS14` drops about 0.35 V, so an external 5.0 V arrives at 4.65 V,
always below USB VBUS. USB wins, the Schottky is reverse biased, nothing flows
back. 4.65 V is comfortably above what the module regulator needs.

**This only holds if the converter is set to 5.0 V.** At 5.5 V it becomes
5.15 V after the diode, above USB, and it back feeds. Hence the `5,0 V MAX`
silkscreen next to the terminal. It is an instruction, not a suggestion.

## Bring up

Never plug a new board straight into the motors.

1. Continuity: `MOT_Jn` pad *k* to `CONTROL_Jn` pad *k*, four connectors, five
   pins, twenty measurements. Then confirm no continuity between neighbours.
2. Power alone, 5.0 V on the terminal, nothing else connected. The green LED
   lights. Measure at the jumper output: **4.65 V**. Reading 5.0 V means the
   Schottky is reversed or shorted, and the computer must not be connected.
3. Current draw of a few milliamps. Above 100 mA, stop and find the short.
4. Fit the ESP32. Nothing should get warm.
5. One motor only, robot off, turn the wheel by hand. Three LEDs blink in
   sequence. One dead LED is a sensor or a wire, not the board.

## Status

Schematic complete, ERC clean. Board is 120 x 79 mm, 2 layers, placement
frozen and routed. Silkscreen and fabrication output pending.

The French specification with the full component list is in
[`specification-fr.md`](specification-fr.md).

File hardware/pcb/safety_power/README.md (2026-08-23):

# Power distribution board

Takes the battery rail and fans it out to three buses, each independently
fused, with the protections the traction chain needs.

## The battery, decoded

The pack is marked `10INR19/66-4`, an IEC 61960 designation:

| | |
|---|---|
| `10` | ten cells in series |
| `INR` | lithium NMC, cylindrical |
| `19/66` | 18650 format |
| `-4` | four in parallel |

So 10S4P, 12800 mAh, and 12800 / 4 = **3200 mAh per cell**. Check: 37 x 12.8 =
473.6 Wh against the 474 Wh on the label.

**The rail is not 37 V, it is 30 to 42 V.** 37 V is only the nominal figure.
Full charge at 4.2 V per cell is 42.0 V, BMS cutoff at 3.0 V per cell is 30.0 V.

Every part on this rail must therefore be rated for 42 V with margin, which in
practice means **choosing 60 V parts**. A converter sold as "8 to 40 V", the
most common category on the market, is destroyed by the first full charge. This
is the single most common way this kind of board dies.

## Current, and why the 100 A breaker was wrong

3200 mAh 18650s are energy cells, not power cells, typically 2C to 3C
continuous. Four in parallel gives 26 to 40 A at cell level, and the BMS on a
pack like this usually limits first, around 20 to 30 A continuous.

A 100 A breaker will never trip before the BMS cuts or the cabling heats.
Protection that never acts before the thing it protects is decorative, and
worse, it leaves the BMS absorbing the entire fault. **The main fuse is 40 A.**

| Element | Protects |
|---|---|
| BMS | the cells: over discharge, overcharge, temperature |
| 40 A main fuse | the cabling, against a hard short |
| Branch fuses | each load, independently of the others |

## Architecture

```
Battery 10S4P, 30 to 42 V
  -> BMS  ->  manual isolator  ->  40 A fuse  ->  distribution board
       bus 37 V   30 A motor controllers | 5 A to 12 V | 3 A to 5 V | 5 A spare
       bus 12 V   SBC | fans | LIDAR | spare
       bus  5 V   Hall board and ESP32 | sensors | spare
```

The onboard computer is a **youyeetoo X1**, which takes **12 V** and a 3 A
supply. There is therefore no 19 V rail: the computer shares the 12 V bus with
the fans and sensors, and the board needs two converters, not three.

Converters are specified by requirement rather than part number, because
availability moves. The eliminating criterion is the input range: **20 to 60 V
minimum**, 12 V at 8 A and 5 V at 5 A out.

They are carried as **replaceable modules on a carrier board**. Designing a
60 V, 8 A switcher from scratch is a project of its own, and a module that
fails is swapped in two minutes instead of condemning the board.

## Protections

| Against | Choice |
|---|---|
| Reverse polarity | keyed connectors, XT90 or Anderson. A diode at 30 A would burn 20 W; a connector that cannot be plugged backwards costs nothing and never heats |
| Bus overvoltage | `SMCJ48A` TVS, 48 V standoff, above the 42 V maximum |
| Regeneration spikes | 2 x 470 uF, 63 V, low ESR |
| Hard short | 40 A main fuse |
| Branch fault | automotive blade fuses in PCB holders |

### Regeneration is the failure nobody plans for

Four hub motors become generators on any downhill or braking. Current flows
back toward the battery and the bus voltage rises. If the BMS disconnects at
that moment, on a full pack, the current has nowhere to go and the bus can
climb well above 42 V within milliseconds. This is what kills power boards on
hub motor robots. The bulk capacitance and the TVS are not optional.

## Copper

IPC-2221, external layer, 30 C rise:

| Current | 1 oz | 2 oz | 3 oz |
|---|---|---|---|
| 40 A | 24.6 mm | 12.3 mm | 8.2 mm |
| 30 A | 16.5 mm | 8.3 mm | 5.5 mm |
| 10 A | 3.6 mm | 1.8 mm | 1.2 mm |

**2 oz copper**, 37 V bus poured 10 mm wide on both faces and stitched with
vias every 5 mm. An ordinary two layer board carries 30 A that way; no bolted
busbar is needed.

## Precharge

The build uses a manual isolator, no contactor. The motor controllers have
large input capacitors which, at the instant the isolator closes, behave as a
short: several hundred amps for a few milliseconds, an arc, and contacts that
pit a little more each time.

A **100 R, 10 W resistor** permanently across the isolator, or in series with a
momentary button, fixes it. Press for two seconds, the capacitors charge
gently, then close the isolator onto an already equalised voltage. It lives on
the loom, not on the board.

## Status

Specified, not yet drawn. Blocking item: the BMS continuous rating from the
pack label, which sets every figure downstream. The full French specification
is in [`specification-fr.md`](specification-fr.md).

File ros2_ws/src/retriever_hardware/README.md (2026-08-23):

# retriever_hardware

The `ros2_control` SystemInterface. Talks to the microcontrollers over
SocketCAN using the frame layout generated from `firmware/protocol/protocol.yaml`.

Supports three modes: mock, loopback on a virtual CAN interface, and real
hardware. The first two let the entire stack be tested in continuous
integration without a robot.

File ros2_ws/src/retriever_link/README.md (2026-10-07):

# retriever_link

The link layer, computer side: two interchangeable transports behind one
interface, and the node that turns frames into standard ROS 2 messages.

| | |
|---|---|
| `SerialTransport` | COBS framing over a USB serial port. The bench transport. |
| `SocketCanTransport` | CAN 2.0A over SocketCAN. Written, never run — the board does not exist yet. |
| `link_bridge` | Publishes `/imu/data`, `/imu/mag`, link and node status, diagnostics, and firmware logs into `/rosout`. |

The framing is not reimplemented here. This package compiles the same C files
as the firmware, from `firmware/components/retriever_link/portable/`. One
implementation, so the two ends of the cable cannot disagree.

`imu_conversion.cpp` holds everything about units, frames and covariances, in a
translation unit with no ROS node and no hardware, tested on its own. Silent
conversions are what make EKFs diverge, and they read better alone.

See `docs/architecture/13-architecture-logicielle-liaison.md`, sections AB and AF.

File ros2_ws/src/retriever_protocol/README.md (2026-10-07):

# retriever_protocol

The wire protocol, generated from `firmware/protocol/protocol.yaml`.

**Nothing here is written by hand.** Edit the YAML, then run
`python3 firmware/protocol/generate.py`. CI fails if the two drift apart.

The C header in this package is byte for byte the one compiled into the ESP32
firmware, so a serialisation disagreement between the robot and the computer is
structurally impossible rather than merely unlikely. The C++ header is a thin
C++17 wrapper over it — it adds types, not logic.

Each frame carries a 32 bit hash of the protocol's *meaning*, not of the file's
text: fixing a typo in a comment does not force a reflash, changing a scale
factor does. Every heartbeat reports it, and a mismatch is a refusal to arm.

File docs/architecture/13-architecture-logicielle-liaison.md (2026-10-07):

# Architecture logicielle — couche de liaison et premier capteur

**Version** : 1.0 — 11 septembre 2026
**Portée** : sections **AA** à **AH**. Complète le dossier v1.2 ; ne le remplace pas.
**Prérequis de lecture** : `02-comms-esp32-moteurs.md` (§F, §G), `03-ros2-etats-boot.md` (§I), `11-corrections-v1.2.md` (C14, C15).

| Marqueur | Signification |
|---|---|
| ✅ **VÉRIFIÉ** | Datasheet constructeur, norme, ou REP officiel. |
| 🟡 **CONSENSUS** | Sources indépendantes concordantes. |
| 🔴 **À MESURER** | Inconnu ou contradictoire. **Interdiction de figer avant mesure.** |
| ⚠️ **RISQUE** | Point de conception dangereux si mal traité. |
| 📐 **HYPOTHÈSE** | Valeur posée faute de donnée ; à confirmer. |

---

# AA. Le problème, et la décision qui en découle

## AA.1 La situation, posée franchement

Le dossier v1.1 tranche : **le bus temps réel est un bus CAN** (§A.1-1, §F.1). Cette décision est bonne et n'est pas rediscutée ici. Mais elle a une conséquence de calendrier que le dossier n'adresse pas :

> La carte `safety_bus_distribution` n'est pas fabriquée. Aucun transceiver n'est câblé. Le §11 Partie 6 place cette carte à l'**étape 1** de l'ordre de fabrication, et le dossier place la navigation autonome à l'**étape 5** du plan de build.

Autrement dit : le logiciel ne peut pas commencer tant que le matériel de communication n'existe pas. C'est faux, et c'est coûteux — parce que la pile ROS 2, l'intégration des capteurs, les conventions de repères et les covariances représentent plusieurs semaines de travail qui ne dépendent en rien du support physique des trames.

## AA.2 La décision

**On sépare le protocole de son transport, et on développe sur un transport série tout en écrivant le code comme si c'était déjà du CAN.**

Concrètement :

| | Aujourd'hui | Quand la carte existera |
|---|---|---|
| Trame applicative | identifiant 11 bits, ≤ 8 octets | **identique** |
| Plan d'adressage | celui du §F.3 | **identique** |
| Code applicatif firmware | ne voit que `rt_frame_t` | **inchangé** |
| Code applicatif ROS 2 | ne voit que `protocol::Frame` | **inchangé** |
| Transport firmware | `link_uart.c` | `link_twai.c` — un fichier |
| Transport ROS 2 | `serial_transport.cpp` | `socketcan_transport.cpp` — un fichier |
| Bascule | — | une option Kconfig, un paramètre de lancement |

Les deux fichiers CAN sont **déjà écrits**. Ils ne sont pas de la prévoyance : ce sont la preuve que l'abstraction est de la bonne taille. S'il avait fallu plus qu'un fichier de chaque côté, c'est que la séparation aurait été mal placée, et il aurait mieux valu s'en apercevoir maintenant que dans trois mois.

## AA.3 Ce que la contrainte des 8 octets apporte, gratuitement

La charge utile est plafonnée à 8 octets **même en série**, où rien ne l'impose. C'est délibéré, et ce n'est pas de la discipline pour la discipline :

- un protocole conçu à l'aise en série ne rentrerait jamais dans CAN 2.0A, et le portage serait une réécriture ;
- la contrainte force à réfléchir à ce qui mérite d'être transmis à 100 Hz — exercice sain ;
- le calcul de charge de bus reste valable d'un transport à l'autre, donc on ne le refait pas.

⚠️ Le seul coût est là où il se voit : **il n'y a pas de place pour un horodatage dans les trames IMU**. Le §AF.4 dit ce qu'on fait à la place, et ce que ça coûte réellement.

---

# AB. La couche de liaison

## AB.1 La trame canonique

```c
typedef struct {
    uint16_t id;        /* 11 bits, plan d'adressage du §F.3 */
    uint8_t  dlc;       /* 0..8 */
    uint8_t  data[8];
} rt_frame_t;
```

C'est le **seul** type que voient les couches supérieures, des deux côtés de la liaison. En CAN, il correspond octet pour octet à une trame de données standard. En série, il est encadré (§AC).

## AB.2 L'interface d'un transport

Trois opérations côté firmware, trois côté calculateur. C'est la mesure exacte de ce qu'il faut réécrire pour changer de support.

```
firmware                          calculateur (C++)
  init(config)                      open()
  send(frame)                       send(frame)
  poll(timeout) → deliver(frame)    receive(frame, timeout)
  stats(out)                        stats()
```

## AB.3 L'architecture d'émission côté firmware

```
   tâche IMU ─────────► file normale  (64 trames) ──┐
   entretien ─────────►                             ├──► tâche TX ──► transport
   crochet RX ────────► file urgente  ( 8 trames) ──┘      prio 20
                                                            (urgente d'abord)
```

⚠️ **La file urgente n'est pas l'arbitrage CAN, et il ne faut pas la prendre pour tel.** Elle ordonne les trames *à l'intérieur d'un nœud*. L'arbitrage CAN, lui, ordonne les trames **entre nœuds**, sur le fil, sans qu'aucun logiciel n'intervienne. Aucune file logicielle ne reproduit cela.

## AB.4 Le dimensionnement des files

| File | Taille | Raison |
|---|---|---|
| TX normale | 64 trames | 3 trames par échantillon IMU à 100 Hz = 300/s. 64 trames couvrent ~200 ms d'à-coup sans perte. |
| TX urgente | 8 trames | Elle ne doit jamais se remplir. Si elle se remplit, le lien est mort et il faut le savoir, pas l'absorber. |
| RX | 32 trames | Le trafic descendant est événementiel (TIME_SYNC à 1 Hz, PING à 1 Hz). |

**Règle absolue** : une file pleine fait **perdre** la trame et incrémenter un compteur. Elle ne bloque jamais l'appelant. Une boucle de contrôle qui attend une liaison saturée est une boucle de contrôle qui a cessé de contrôler.

## AB.5 ⚠️ Ce que le transport série ne fournit pas

C'est la section la plus importante de ce document. Elle existe pour qu'aucune décision future ne s'appuie par inadvertance sur une garantie qui n'existe pas.

| Propriété | CAN 2.0A | Série + COBS |
|---|---|---|
| Arbitrage par priorité, non destructif | ✅ matériel | ❌ approximé par une file logicielle, dans un seul nœud |
| Acquittement par les récepteurs | ✅ | ❌ |
| Retransmission automatique | ✅ | ❌ |
| Confinement de défaut (error-passive, bus-off) | ✅ | ❌ |
| Détection d'erreur | CRC-15 + bourrage + ACK | CRC-16 seul |
| Multipoint sur deux fils | ✅ | ❌ un câble par nœud |
| Immunité EMI près des hacheurs | ✅ paire différentielle | ❌ asymétrique |
| Latence bornée | ✅ | 🟡 bornée en pratique, pas par construction |

**Conséquences de conception, non négociables :**

1. **Aucune fonction de sécurité n'est validée sur le transport série.** Les niveaux N4 et N5 de la chaîne d'arrêt sont matériels et le restent. Le banc série ne sert jamais à prononcer une recette de sécurité.
2. **Le nœud SAFETY, sur le banc, n'a aucune autorité.** Le mot « safety » dans son nom décrit sa destination, pas son état.
3. **Aucun moteur ne tourne sur liaison série.** La chaîne `CMD_WHEELS` → variateur attend le CAN. Elle est décrite dans `protocol.yaml`, générée, et marquée `planned` : rien ne l'émet.
4. **Le passage au CAN ne se fait pas « quand ça marchera bien en série ».** Il se fait quand la carte existe, et il est suivi de la recette complète du §Q niveau 2 — débranchement du bus en marche, terminaison retirée, trame corrompue injectée. Aucun de ces tests n'a d'équivalent en série.

## AB.6 Ce que coûte réellement le passage au CAN

| Étape | Ce qu'il faut faire |
|---|---|
| Firmware | `idf.py menuconfig` → Retriever → Liaison → cocher « Utiliser le bus CAN ». Recompiler. |
| ROS 2 | `transport: "socketcan"` dans `link_bench.yaml`. |
| Linux | `ip link set can0 up type can bitrate 500000 restart-ms 100` |
| Matériel | Transceiver `TCAN1042HV` avec `STB` à la masse (§C5), terminaisons 120 Ω **aux deux extrémités physiques uniquement**, `GPIO5` haut au boot. |
| Vérification | §Q niveau 2 en entier. Pas un sous-ensemble. |

⚠️ Aucune ligne de `imu_bno085.c`, de `bridge_node.cpp`, de `imu_conversion.cpp` ni de `protocol.yaml` ne change. Si l'une d'elles doit changer, c'est un défaut d'architecture et il faut le traiter comme tel.

## AB.7 Écarts assumés par rapport au §F.3

| Point | §F.3 | Ici | Pourquoi |
|---|---|---|---|
| `HEARTBEAT` | DLC 4 | **DLC 8** | Le §K.2 [P3] exige que le heartbeat porte le hash du protocole. Quatre octets ne suffisent pas à porter état + uptime + erreurs + hash. |
| `IMU_GYRO_ACC` (0x211) | « 8+8 → 2 trames » | **0x211 gyro, 0x212 accel** | Deux identifiants explicites valent mieux qu'une trame de 16 octets qui n'existe pas en CAN 2.0A. |
| — | — | **0x213 `IMU_STATUS`** | La qualité d'orientation doit remonter : c'est elle qui alimente la covariance (§AF.5). Les 8 octets de `IMU_QUAT` sont pleins. |
| — | — | **0x214 `IMU_MAG`** | Diagnostic magnétique. Le §N.3 désigne le magnétomètre comme le maillon faible ; encore faut-il pouvoir le mesurer. |
| — | — | **0x330/0x331 `LINK_PING`/`PONG`** | Le §Q niveau 2 demande une latence aller-retour applicative. Il faut une trame pour ça. |
| — | — | **0x7F0 `LOG`** | Tunnel de journalisation (§AC.5). |
| Renommage | `retriever_can`, `retriever_can_bridge` | **`retriever_protocol`**, **`retriever_link`** | Appeler « can » une couche qui abstrait le transport serait contredire l'architecture dans le nom des paquets. |

---

# AC. Le cadrage série

## AC.1 Le format sur le fil

```
   paquet, avant encodage :

   ┌────────┬────────┬─────────────────────────┬────────┬────────┐
   │ id_bas │ id_h+dlc│         données         │ CRC bas│ CRC ht │
   └────────┴────────┴─────────────────────────┴────────┴────────┘
       0        1              2 .. 2+dlc-1

   octet 1 = ((id >> 8) & 0x07) | (dlc << 4)
   CRC-16/CCITT-FALSE des octets précédents, petit-boutiste

   puis : encodage COBS de l'ensemble, puis un octet 0x00

   trame pleine (8 octets utiles)  →  14 octets sur le fil
   2 en-tête + 8 données + 2 CRC + 1 COBS + 1 délimiteur
```

## AC.2 Pourquoi COBS et pas SLIP

Les deux résolvent le même problème : réserver un octet comme délimiteur et le faire disparaître des données.

| | SLIP | **COBS** |
|---|---|---|
| Surcoût typique | 0 | 1 octet |
| Surcoût **pire cas** | ❌ **×2** (paquet entier d'octets d'échappement) | ✅ 1 + ⌈n/254⌉ |
| Resynchronisation | au délimiteur | au délimiteur |
| Coût CPU | comparable | comparable |

Le pire cas décide. Sur une liaison budgétée au plus juste, **un format dont le pire cas est imprévisible est un format qu'on ne peut pas dimensionner** — et un budget qu'on ne peut pas garantir est un budget qu'on découvre dépassé le jour où les données contiennent beaucoup de zéros, c'est-à-dire exactement quand le robot est à l'arrêt.

Référence : Cheshire & Baker, *Consistent Overhead Byte Stuffing*, IEEE/ACM Transactions on Networking, 1999.

## AC.3 Le débit, et pourquoi 921 600 et pas 115 200

Les chiffres viennent directement de `protocol.yaml` — ils sont recalculés à chaque génération, dans `docs/architecture/generated/protocol-tables.md`.

| Charge | Trames/s | Octets/s | @ 115 200 | @ 921 600 |
|---|---:|---:|---:|---:|
| **Banc B1** (IMU seule) | 330 | 4 620 | **40 %** | **5,0 %** |
| **Robot complet** (§F.3 en entier) | 695 | 9 400 | **82 %** | **10,2 %** |

Le banc tiendrait à 115 200. Le robot complet, non — 82 % d'occupation sur une liaison sans contrôle de flux, c'est une liaison qui perd des trames dès le premier à-coup d'ordonnancement.

**Donc on prend 921 600 tout de suite.** Ce n'est pas de l'excès de zèle : c'est l'économie d'une séance de débogage sur un symptôme (« l'IMU saute par moments ») dont la cause (« la liaison est saturée ») ne se voit pas depuis le symptôme. ✅ Le pont CP2102N de la DevKitC supporte 921 600.

## AC.4 La détection d'erreur, honnêtement

**CRC-16/CCITT-FALSE**, polynôme `0x1021`, initialisation `0xFFFF`, sans réflexion ni XOR final. Vecteur de référence : `CRC("123456789") = 0x29B1`, vérifié par `test_framing.c`.

🟡 Distance de Hamming 4 sur des données bien plus longues que nos paquets de 12 octets : toute erreur de 1, 2 ou 3 bits est détectée, ainsi que toute rafale de 16 bits ou moins (tables de Koopman).

⚠️ **Ce n'est pas l'équivalent du CAN.** Le CAN ajoute au CRC-15 un acquittement et une retransmission automatique : une trame corrompue est **réémise**. Ici, elle est **jetée**, et c'est tout. `test_framing.c` vérifie exhaustivement qu'un bit retourné n'importe où dans une trame ne produit jamais une trame acceptée — mais produire zéro trame n'est pas la même chose que produire la bonne.

Le comportement en cas de rafale de bruit est également testé : **on perd au plus une trame**, celle qui se colle au bruit, et le décodeur se recale au délimiteur suivant.

## AC.5 Le tunnel de journalisation

Sur une DevKitC, la console ESP-IDF et la liaison partagent l'UART0 et le même pont USB. Trois options, et une seule qui ne coûte rien :

| Option | Coût |
|---|---|
| Perdre les journaux du firmware | ❌ inacceptable pour une mise au point |
| Liaison sur UART2, console sur UART0 | un second adaptateur USB-série, un second câble |
| **Journaux tunnellisés en trames `LOG`** | ✅ un seul câble — **retenu** |

L'effet secondaire est ce qui emporte la décision : **les journaux du firmware arrivent dans `/rosout`**, horodatés par ROS, enregistrés dans les bags, visibles dans Foxglove au même endroit que tout le reste. Une ligne de firmware et une ligne de Nav2 deviennent comparables dans le temps.

Trois règles dans l'implémentation, dans cet ordre :

1. **Ne jamais bloquer** — un fragment qui ne rentre pas en file est perdu et compté.
2. **Ne jamais récurser** — si le transport journalise, le tunnel ne rejournalise pas.
3. **Ne jamais passer devant** — file normale, jamais la file urgente.

⚠️ **Ce que le tunnel ne couvre pas.** Il détourne les `ESP_LOGx`, et rien d'autre. Continuent d'écrire en clair au milieu des paquets : les messages du **bootloader ROM** (à 115 200, au démarrage), le **gestionnaire de panique** et la trace d'exception, l'abandon sur `ESP_ERROR_CHECK`, les débordements de pile signalés par FreeRTOS, et tout `printf()`.

Le décodeur les rejette et se recale, donc la liaison survit. Mais c'est précisément la trace de plantage — celle qu'on veut le plus — qui arrive hachée. Pour la lire proprement : un adaptateur sur UART2, ou l'option à `n`. C'est un compromis assumé, pas un oubli.

---

# AD. Le protocole comme source unique

## AD.1 Le principe, et le mode de défaillance qu'il évite

Le §P.2-1 pose la règle : une source de vérité par donnée. Pour le protocole, la source est `firmware/protocol/protocol.yaml`, et **rien n'est recopié à la main** :

```
                       firmware/protocol/protocol.yaml
                                    │
                         generate.py│
            ┌───────────────────────┼───────────────────────┐
            ▼                       ▼                       ▼
   retriever_protocol.h      protocol.hpp       protocol-tables.md
      (C99, firmware)      (C++17, ROS 2)         (documentation)
            │                       │
            └── même fichier ───────┘
                compilé des deux côtés

   tools/retriever_wire.py lit le YAML À L'EXÉCUTION
   → troisième implémentation, non générée, donc impossible à désynchroniser
```

Le mode de défaillance visé est précis : **un nœud flashé avec une version du protocole, un calculateur compilé avec une autre**. Il ne produit pas d'erreur franche — il produit des valeurs plausibles et fausses. Un quaternion qui se dégrade lentement parce qu'un champ a bougé d'un octet est un bug qui coûte des jours.

## AD.2 Le hash, et pourquoi il porte sur le sens et non sur le texte

Le générateur calcule un hash SHA-256 tronqué à 32 bits **sur le modèle sémantique** — identifiants, champs, types, offsets, échelles, énumérations — et non sur le texte du fichier.

- Corriger une faute dans un commentaire **ne change pas le hash**, donc ne force pas à reflasher trois nœuds.
- Changer une échelle, un identifiant ou l'ordre d'un champ **change le hash**, donc l'impose.

Ce hash est compilé dans le firmware et remonté dans chaque `HEARTBEAT`. Le nœud ROS le compare au sien. ⚠️ Une divergence est un **refus d'armement**, pas un avertissement (§K.2 [P3]) — sur le banc, c'est un diagnostic `ERROR` et un message qui dit quoi faire.

## AD.3 Ce que la CI vérifie

`tools/check_protocol_sync.py`, trois étapes :

1. **Les fichiers générés correspondent-ils au YAML ?** Sinon, quelqu'un a édité le YAML sans régénérer, ou édité un fichier généré à la main.
2. **Le C et le Python produisent-ils les mêmes octets ?** Vérifié sur les 28 trames, à travers le cadrage complet — COBS et CRC compris.
3. **Les vecteurs d'or tiennent-ils ?** Le format du fil est figé : un enregistrement d'aujourd'hui doit rester lisible dans six mois.

⚠️ Les vecteurs d'or ne sont pas décoratifs. Sans eux, une modification du générateur peut changer silencieusement le format du fil : le firmware et ROS resteraient d'accord entre eux, et tous les deux d'accord sur le mauvais format. Rien n'échouerait, et les bags passés deviendraient illisibles.

---

# AE. Le socle firmware

## AE.1 Choix de la chaîne d'outils

**ESP-IDF v5.5, pas PlatformIO, pas Arduino.** Le dossier §P.1 mentionnait `platformio.ini` ; c'est corrigé ici.

| | Raison |
|---|---|
| ESP-IDF | FreeRTOS exposé directement, Kconfig, contrôle des piles et des priorités, TWAI natif, pas de couche Arduino qui masque les latences |
| v5.5 et non v6.1 | ✅ v6.1 est la version stable actuelle (août 2026), mais v6.0 a supprimé les pilotes hérités et la documentation communautaire — BNO08x, TWAI, PCNT — est encore massivement sur 5.x. 📐 v5.5 est supportée 30 mois à compter de sa sortie mi-2025, donc bien au-delà de l'horizon du projet. La migration vers 6.x est un élément de plan, pas une urgence. |

## AE.2 Arborescence

```
firmware/
├── protocol/
│   ├── protocol.yaml            ◄── SOURCE UNIQUE
│   ├── generate.py
│   └── generated/retriever_protocol.h
├── components/                  ◄── partagés SAFETY et MOTION
│   ├── retriever_protocol/      en-tête généré
│   ├── retriever_link/
│   │   ├── portable/            C99 pur — compilé AUSSI par ROS 2
│   │   │   ├── rt_cobs.c/.h
│   │   │   ├── rt_crc16.c/.h
│   │   │   └── rt_framing.c/.h
│   │   └── src/  link.c  link_uart.c  link_twai.c  link_log.c
│   └── retriever_imu/
│       ├── src/imu_bno085.c            interface minimale
│       ├── src/sh2_hal_esp32_spi.c     le portage, c'est NOTRE code
│       └── vendor/sh2/                 sous-module CEVA, Apache 2.0
├── esp32_safety/                projet ESP-IDF
└── test/                        tests hôte, sans matériel
```

Le répertoire `portable/` mérite qu'on s'y arrête : **ces trois fichiers C sont compilés à l'identique par le firmware ESP32, par le nœud ROS 2 et par les tests hôte.** Les recopier dans le paquet ROS serait plus commode à empaqueter, et garantirait qu'ils divergent un jour. Le dépôt est un seul projet (§P.2-2) : le chemin relatif est légitime, et `-DRETRIEVER_FIRMWARE_DIR=` permet de construire hors du dépôt si le besoin se présente.

## AE.3 La pile SH-2 n'est pas réécrite

Le BNO085 parle SHTP : une pile à états, avec des numéros de séquence par canal, un contrôle de flux et une gestion de reset. CEVA la publie sous **Apache 2.0** ✅ — la licence du code de ce projet.

**On l'attache en sous-module, épinglée sur `v1.4.0`, et on n'y touche pas.** Ce qui appartient au projet, c'est le portage : `sh2_hal_esp32_spi.c`, cinq fonctions. Réimplémenter SHTP serait recopier un travail déjà fait, déjà débogué, sous une licence compatible — et hériter de ses bugs sans hériter de ses corrections.

```
git submodule update --init --recursive       # ou tools/fetch_firmware_deps.sh
```

## AE.4 Tâches et priorités

| Tâche | Prio | Période | Rôle |
|---|:-:|---|---|
| `link_rx` | 23 | événementiel | lecture, décodage, crochet, mise en file |
| `link_tx` | 20 | ≤ 20 ms | file urgente d'abord, puis file normale |
| `imu` | 18 | sur `H_INTN` | `sh2_service()`, assemblage du triplet |
| `imu_pub` | 17 | sur échantillon | emballage et émission des trames |
| `house` | 5 | 100 ms | heartbeat, compteurs, journal périodique |

Réservé pour la suite : la tâche `CONTROL` du §G.4, priorité **24**, période 5 ms — au-dessus de tout ce qui précède. C'est pour elle que la place est laissée.

⚠️ **`CONFIG_FREERTOS_HZ=1000`.** Par défaut, FreeRTOS bat à 100 Hz : `pdMS_TO_TICKS(1)` vaut alors un tick de 10 ms, et toute tâche plus rapide que 100 Hz devient impossible à cadencer. C'est la valeur la plus importante de `sdkconfig.defaults`, et c'est celle qu'on oublie.

## AE.5 Les règles du §G.4, et où elles sont appliquées

| Règle | Où |
|---|---|
| Aucune allocation dynamique après l'initialisation | files FreeRTOS créées une fois, tampons statiques partout |
| Aucun appel bloquant dans le chemin temps réel | `rt_link_send(f, 0)` ou `(f, 1 tick)`, jamais `portMAX_DELAY` |
| Limites de sécurité en dur | à venir avec la FSM ; aucune limite n'est configurable par CAN |
| **État sûr en premier** | `hw_init_safe_state()` est le premier appel d'`app_main()` |
| Tout compteur d'erreur est publié | `rt_link_stats_t` → `HEARTBEAT` → `/retriever/link_status` → `/diagnostics` |
| Le protocole vient du fichier généré | aucune constante de protocole recopiée à la main |

`hw_init_safe_state()` est aujourd'hui **vide** : sur le banc, il n'y a ni contacteur, ni ligne `/SAFE`, ni variateur à mettre en sécurité. La fonction existe et est appelée en premier pour que, le jour où elle aura un contenu, l'ordre des opérations n'ait pas à être rediscuté.

---

# AF. La chaîne ROS 2

## AF.1 Le graphe, aujourd'hui

```
   ESP32-SAFETY ──série 921600──► retriever_link_bridge ──┬──► /imu/data            (sensor_msgs/Imu)     100 Hz
                                                          ├──► /imu/mag             (MagneticField)        10 Hz
                                                          ├──► /retriever/imu_status                       10 Hz
                                                          ├──► /retriever/link_status                       2 Hz
                                                          ├──► /retriever/node_status                      10 Hz
                                                          ├──► /diagnostics                                 2 Hz
                                                          ├──► /rosout    ← journaux du firmware
                                                          └──► /tf        ⚠️ banc uniquement
                                                                    │
                                                          foxglove_bridge ──ws://…:8765──► Foxglove Studio
```

## AF.2 Les paquets

| Paquet | Contenu |
|---|---|
| `retriever_protocol` | en-têtes générés, aucune dépendance ROS |
| `retriever_msgs` | `ImuStatus`, `LinkStatus`, `NodeStatus` |
| `retriever_link` | les deux transports, la conversion, le nœud `link_bridge` |
| `retriever_bringup` | `bench_imu.launch.py`, `config/link_bench.yaml` |

**Il n'y a pas de message maison pour l'IMU.** C'est `sensor_msgs/Imu`, et c'est non négociable : tout ce qui suit dans la pile — `robot_localization`, `nav2_collision_monitor`, `imu_filter_madgwick` si un jour il sert, Foxglove, `rosbag2` — attend ce type. Un message maison ferait de chaque consommateur un adaptateur à écrire.

## AF.3 Les conventions de repères, résolues une fois pour toutes

C'est le point qui fait perdre le plus de temps, alors il est tranché ici.

**Le repère monde.** ✅ Le Rotation Vector du BNO085 est référencé au nord magnétique et à la gravité, dans la convention Android : **ENU** — x est, y nord, z haut. ✅ REP-103 impose exactement la même convention aux repères monde de ROS. **Il n'y a donc aucune conversion de repère monde à faire, et en faire une serait une erreur.**

**Le repère capteur.** ✅ Le BNO085 utilise le repère Android : X vers la droite du boîtier, Y vers le haut dans le plan de la face, Z sortant de la face. C'est un repère **direct**, donc l'inversion d'axe que prévoit REP-145 pour les capteurs indirects ne s'applique pas.

**Le montage.** ⚠️ **Le firmware n'applique AUCUNE rotation de montage.** Il publie ce que le capteur mesure, dans les axes du capteur. Le passage du repère capteur au repère du robot est décrit **une seule fois, dans l'URDF**, par la position de `imu_link` par rapport à `base_link`.

C'est la manière ROS de faire, et surtout c'est la seule qui reste vraie quand on démonte le capteur pour le remonter autrement : on corrige un fichier, pas un firmware, et `robot_localization` lit la correction dans TF sans qu'on lui dise rien.

⚠️ Corollaire pour le banc : tant que `imu_link` n'est pas placé dans l'URDF, l'orientation affichée est celle du **boîtier**, pas celle du robot. C'est normal. Le test des six faces du §Q niveau 3 est ce qui validera le placement URDF, et il ne peut pas être fait avant.

## AF.4 L'horodatage, et ce qu'il vaut

Les huit octets d'une trame IMU sont pleins : il n'y a pas de place pour un horodatage. Le §F.4 décrit une régression linéaire `t_ros = a·t_local + b` alimentée par `TIME_SYNC` — elle suppose un horodatage par échantillon qui n'existe pas dans le plan d'adressage du §F.3.

**Ce qui est fait à la place :**

```
   t_message = now() − latency_offset
```

où `latency_offset` est une **constante mesurée**, pas devinée. `LINK_PING` / `LINK_PONG` donnent l'aller-retour applicatif ; la moitié de sa médiane est l'aller simple. `link_monitor.py` affiche directement la valeur à reporter dans `link_bench.yaml`.

| | |
|---|---|
| Gigue attendue | 📐 1 à 2 ms — transmission série (152 µs pour 14 octets à 921 600) plus la granularité de scrutation du pont USB |
| Suffisant pour | un EKF à 30 Hz, une odométrie à 50 Hz — c'est la précision que le §F.4 annonçait déjà |
| Insuffisant pour | de la datation fine d'événements, un couplage serré avec un lidar |
| Si ça devient insuffisant | ajouter une trame d'horodatage dédiée — le plan d'adressage a de la place — et alors seulement mettre en œuvre la régression du §F.4 |

Les trois trames d'un même échantillon portent le **même compteur `seq`**, et le pont refuse d'assembler un quaternion et une accélération qui ne viennent pas du même instant. ⚠️ C'est un cas qu'un EKF ne sait pas détecter : mélanger deux échantillons produit des données parfaitement plausibles et fausses.

## AF.5 Les covariances — la partie qui fait diverger les EKF

⚠️ **Une matrice de covariance à zéro ne signifie pas « pas d'information ». Pour un EKF, elle signifie « confiance infinie ».** C'est la façon la plus efficace de faire diverger une localisation, et elle ne produit aucun message d'erreur. Le §I.2 du dossier le signalait déjà pour le GPS ; il vaut identiquement pour l'IMU.

**Orientation.** Matrice diagonale, `diag(σ_roulis², σ_tangage², σ_lacet²)`.

| Terme | Valeur | Source |
|---|---|---|
| Roulis, tangage | 3,5° = 0,0611 rad | ✅ erreur dynamique de la datasheet BNO08x. Ces deux angles sont observés par la gravité : ils sont bons et stables. |
| Lacet, plancher | 5° = 0,0873 rad | ✅ §I.2 du dossier, « en pratique typiquement 5° ». On ne croit pas le capteur en dessous, même quand il s'annonce meilleur. |
| Lacet, valeur courante | `max(estimation du capteur, plancher)` | Le BNO085 fournit une estimation d'erreur de cap en radians ; c'est elle qui sert. |
| Lacet, si non fourni | 1 rad ≈ 57° | 📐 cas du *game rotation vector*, qui n'a aucune référence de cap. Déclarer le lacet **inconnu** est exact ; publier 0 serait un mensonge. Le firmware le signale par la sentinelle **6,5535 rad** — la borne haute exacte de l'encodage — que le pont reconnaît. |

⚠️ 📐 **Hypothèse assumée** : la covariance est diagonale dans les axes du capteur, et l'incertitude de cap est portée par l'axe z du capteur. Ce n'est exact que si le capteur est à peu près horizontal — l'incertitude de cap est en réalité autour de la verticale du lieu. Sur terrain plat, l'écart est négligeable ; sur une pente forte, il ne l'est plus. Le jour où ça compte, la correction consiste à tourner `diag(σ_rp², σ_rp², σ_lacet²)` du monde vers le capteur, pas à bricoler les écarts types.

**Gyromètre et accéléromètre.** 📐 Valeurs par défaut `0,01 rad/s` et `0,1 m/s²` — des ordres de grandeur, pas des spécifications. **Elles doivent être remplacées par la mesure du banc** (§AG, point 6). Une covariance inventée qui traîne trois mois est une dette qui se paie au moment où l'EKF se met à dériver sans raison apparente.

**Donnée absente.** ✅ REP-145 : premier élément de la matrice à `-1`. C'est la seule manière normalisée de dire « non fournie » ; laisser des zéros dirait « parfaitement connue ».

## AF.6 Les autres garanties de `/imu/data`

| Garantie | Pourquoi elle compte |
|---|---|
| **Quaternion normalisé** | La quantification Q14 laisse `‖q‖` s'écarter de 1 de quelques 1e-4. Un quaternion non unitaire est refusé par certains consommateurs et dégrade les autres en silence. La norme d'entrée est publiée dans `/retriever/imu_status` : au-delà de 1e-2, c'est une corruption. |
| **Accélération gravité comprise** | ✅ REP-145 : +g au repos, axe z vers le haut. Le firmware active `SH2_ACCELEROMETER` et non `SH2_LINEAR_ACCELERATION`. Se tromper ici est invisible jusqu'à ce que l'EKF dérive. |
| **Magnétomètre en teslas** | Le BNO085 donne des µT, `sensor_msgs/MagneticField` attend des T. Facteur 1e-6. L'oubli passe inaperçu tant qu'on ne regarde que la direction. |
| **QoS capteur** | `BEST_EFFORT`, profondeur faible. À 100 Hz, retransmettre un échantillon périmé n'a aucun intérêt, et sur Wi-Fi c'est nuisible (§I.4). |

## AF.7 Le choix de la fusion d'orientation

Trois modes, un seul choix par défaut, et la raison du changement à venir.

| Mode | Cap absolu | Immunité magnétique | Quand |
|---|:-:|:-:|---|
| `ROTATION_VECTOR` (9 axes) | ✅ | ❌ | **Défaut du banc.** C'est le seul mode qui permet de *juger* la qualité magnétique du site. |
| `GAME_ROTATION_VECTOR` (6 axes) | ❌ dérive en lacet | ✅ totale | Probablement le bon choix une fois l'IMU montée : le §N.3 désigne le magnétomètre comme le maillon faible avec quatre moteurs-roues à proximité. Le cap viendra alors du GPS et de l'odométrie. |
| `ARVR_STABILIZED_RV` | ✅ lissé | ❌ | Corrections de cap étalées au lieu d'être appliquées d'un coup. ⚠️ Un saut de cap est très mal digéré par un EKF. |

Le choix est une option Kconfig. 🔴 **La décision finale n'est pas prise et ne peut pas l'être avant la mesure** : publier `/imu/mag` sert précisément à la trancher, en observant de combien la norme du champ s'écarte du champ terrestre local une fois le capteur à sa place et les moteurs alimentés.

## AF.8 Foxglove

`foxglove_bridge` est packagé pour Jazzy ✅ et démarré par `bench_imu.launch.py` (`foxglove:=false` pour s'en passer).

⚠️ **Foxglove n'affiche pas `sensor_msgs/Imu` en 3D.** Il affiche des repères TF et des marqueurs. Pour voir l'orientation bouger, il faut donc lui donner l'un des deux. Le banc fait les deux :

| Panneau | Topic | Ce qu'on y regarde |
|---|---|---|
| **3D** | `/tf` + `/retriever/imu_marker` | Un pavé aux dimensions de la carte, orienté comme le capteur, dans le repère fixe `imu_world`. |
| **Plot** | `/imu/data` | `angular_velocity.z` pour voir le lacet, `linear_acceleration.z` pour voir la gravité. |
| **Raw Messages** | `/retriever/imu_status`, `/retriever/link_status` | Les covariances, les compteurs d'erreur, l'aller-retour. |
| **Diagnostics** | `/diagnostics` | Les trois vérifications du pont, en clair. |

⚠️ **`bench.publish_tf` est à désactiver dès que l'EKF entre en service.** C'est lui qui publie `odom → base_link` ; laisser le pont publier une deuxième transformation depuis l'IMU donnerait deux sources sur la même arête de l'arbre TF — la faute décrite au §I.3. Le nœud émet un avertissement au démarrage quand l'option est active, précisément pour qu'on ne l'oublie pas.

---

# AG. Recette du banc B1

**Critère de sortie** : `/imu/data` à 100 Hz dans Foxglove, covariances renseignées, zéro erreur de liaison sur dix minutes, et l'orientation du pavé 3D suit la carte quand on la tourne à la main.

**Dans l'ordre. Chaque point ne se fait que si le précédent est passé.**

### 1 — Le pontet PS0/PS1 ⚠️ à faire avant de brancher quoi que ce soit

Sur les cartes Adafruit et SparkFun, `PS0` et `PS1` sont strappés pour l'I²C. ⚠️ Tant que le pontet n'est pas modifié, **le composant démarre en I²C et le SPI ne répondra jamais** — sans message d'erreur, parce qu'il n'y a personne pour en émettre un.

`PS1` à 3,3 V, `PS0` au GPIO26, `BOOTN` à 3,3 V par 10 kΩ. Câblage complet dans `board_config.h`.

| Critère | ✅ |
|---|---|
| Pontet I²C ouvert, PS1 haut, PS0 sur GPIO | vérifié au multimètre, carte hors tension |

### 2 — Le protocole est cohérent avant de flasher

```bash
python3 tools/check_protocol_sync.py
make -C firmware/test
```

| Critère | ✅ |
|---|---|
| Trois implémentations d'accord, tests hôte au vert | 0 échec |

### 3 — Le nœud parle

```bash
git submodule update --init --recursive
cd firmware/esp32_safety && idf.py set-target esp32 && idf.py build flash
python3 tools/link_monitor.py --device /dev/ttyUSB0
```

| Critère | ✅ | Si ça échoue |
|---|---|---|
| `HEARTBEAT_SAFETY` à 10 Hz | oui | mauvais port, mauvais débit, ou nœud qui ne démarre pas |
| `crc_errors` et `format_errors` | stables après le démarrage | une croissance continue = débit ou câblage |
| Hash annoncé par le nœud | = celui de `generate.py --hash` | firmware pas à jour |

⚠️ Une bordée d'erreurs **au démarrage** est normale : ce sont les messages du bootloader ROM à 115 200. Ce qui compte est qu'elles cessent.

### 4 — Le capteur répond

Dans les journaux tunnellisés que `link_monitor.py` affiche :

```
[esp32 INFO] bno08x present : firmware x.y.z
```

| Critère | ✅ | Si ça échoue |
|---|---|---|
| `sh2_getProdIds()` répond | oui | dans l'ordre : pontet PS0/PS1, mode SPI 3, `H_INTN` câblé, `BOOTN` haut, horloge ≤ 3 MHz |
| `IMU_QUAT`, `IMU_GYRO`, `IMU_ACCEL` | 100 Hz chacune | si 0 Hz mais le produit répond : rapports refusés, lire le code de retour |
| `reset_count` dans `IMU_STATUS` | **0** | tout autre valeur = alimentation instable ou câblage SPI |

### 5 — La latence, mesurée et non devinée

`link_monitor.py` affiche la médiane de l'aller-retour et la valeur à reporter :

```
  aller-retour  médiane 2.84 ms   max 5.10 ms   →  latency_offset_ms ≈ 1.42
```

| Critère | ✅ |
|---|---|
| `link.latency_offset_ms` reporté dans `link_bench.yaml` | fait, et la valeur mesurée notée dans `docs/measurements/` |

### 6 — Le bruit, mesuré et non deviné

Capteur **immobile**, sur une table stable, 60 secondes :

```bash
ros2 launch retriever_bringup bench_imu.launch.py
ros2 bag record -o /tmp/imu_repos /imu/data          # laisser tourner 60 s
```

Écart type de chaque axe → `imu.angular_velocity_stddev` et `imu.linear_acceleration_stddev`.

| Critère | ✅ | Seuil |
|---|---|---|
| Biais gyro au repos | < 0,02 rad/s | §K.2 [P4] |
| Norme de l'accélération au repos | 9,81 ± 0,3 m/s² | §K.2 [P4] |
| Norme du quaternion | 1,00 ± 0,01 | §K.2 [P4] |
| Valeurs mesurées reportées dans `link_bench.yaml` | fait | remplacent les 📐 |

### 7 — Foxglove

```bash
ros2 launch retriever_bringup bench_imu.launch.py
```

Se connecter à `ws://<adresse>:8765`, monter les quatre panneaux du §AF.8.

| Critère | ✅ |
|---|---|
| Le pavé 3D suit la carte quand on la tourne à la main | oui |
| Les trois diagnostics du pont sont `OK` | oui |
| `/imu/data` à 100 Hz dans le panneau Plot | oui |

### 8 — Endurance

Dix minutes, capteur immobile, tout en marche.

| Critère | ✅ |
|---|---|
| `crc_errors`, `format_errors`, `overflows` | **inchangés** sur les dix minutes |
| `samples_dropped_node`, `samples_dropped_link` | 0 |
| `sensor_resets` | 0 |
| Cadence de `/imu/data` | 100 Hz ± 2 % |

### 9 — Le magnétomètre, pour préparer la décision du §AF.7

Capteur immobile, loin de tout métal, puis à 10 cm d'un moteur-roue non alimenté, puis alimenté.

| Mesure | À noter dans `docs/measurements/` |
|---|---|
| Norme de `/imu/mag` dans chacune des trois situations | Le champ terrestre local vaut 25 à 65 µT. L'écart dit si le cap magnétique restera exploitable — c'est ce qui tranchera entre `ROTATION_VECTOR` et `GAME_ROTATION_VECTOR`. |

---

# AH. Ce que ce document change dans le dossier

## AH.1 Corrections à reporter

| Section | Texte actuel | Correction |
|---|---|---|
| §P.1 | `firmware/*/platformio.ini` | ESP-IDF, pas PlatformIO. Arborescence du §AE.2. |
| §P.1 | `retriever_can/`, `retriever_can_bridge/` | `retriever_protocol/`, `retriever_link/` — le transport est abstrait, le nom ne doit pas dire le contraire. |
| §F.3 | `HEARTBEAT` DLC 4 | DLC 8 — le hash du protocole doit y tenir (§AD.2). |
| §F.3 | `IMU_GYRO_ACC` en deux trames | `0x211` gyro, `0x212` accel, plus `0x213` statut et `0x214` magnétomètre. |
| §F.4 | Régression linéaire par nœud | Non applicable tant qu'aucune trame ne porte d'horodatage. Voir §AF.4. |
| §I.1 | `retriever_can_bridge` | `retriever_link_bridge`. |
| §G.3 | `H_INTN` sur GPIO34 | Sur le banc, GPIO25 : tirage interne disponible. GPIO34 redevient correct sur la carte, où le tirage externe sera au schéma. |

**Corrections issues du banc, 20 septembre 2026.** Chacune est une mesure qui contredit le texte, pas une préférence. Le détail et le mécanisme sont dans `docs/HANDOFF-banc-imu.md` et `docs/HANDOFF-banc-lidar.md`.

| Section | Texte actuel | Correction |
|---|---|---|
| §03, L7 | X4 « double canal », paramètres du constructeur | **Mono-canal en pratique** sur l'exemplaire du banc : `isSingleChannel: true`, `support_motor_dtr: true`, `intensity_bit: 10`, `sample_rate: 5`. Avec les valeurs de la table constructeur, le capteur livre ses informations produit puis aucun scan. Établi par reproduction à l'identique de `tri_test`. |
| §03 | `/scan` conforme REP-117, invalides en `+inf` | **Faux avec ce pilote** : les sans-écho sortent à `0.0` malgré `invalid_range_is_inf: true`. Tout consommateur doit filtrer sous `range_min`. Le taux de couverture se compte sur ce critère — 67 % au banc. |
| §03 | `/scan` à 7 Hz | ~7,5 Hz, **libre et non asservi** : le moteur du X4 n'est pas commandé sur cette carte adaptatrice. La fréquence n'est pas un réglage, c'est une constante du matériel. |
| §AE, §AG.1 | Séquence de reset du BNO085 | **Deux défauts silencieux qui se masquaient** : MOSI doit émettre des zéros pendant les lectures (le SPI est full-duplex et le capteur lit MOSI comme un en-tête SHTP), et le réveil PS0 est indispensable avant chaque écriture. Le second était invisible tant que le premier existait. |
| §AG.4 | « ouvrir le port série » | Sur une DevKitC, DTR et RTS pilotent IO0 et EN par le circuit d'auto-reset : l'ouverture d'un port peut laisser la carte dans le **bootloader ROM**, muette à 921600. Le transport et les outils remettent la carte en mode exécution à l'ouverture (`serial.reset_on_open`). Sur CAN, la question disparaît. |
| §AG.1 | Compteur de resets du capteur | Le reset d'initialisation du BNO085 n'est pas un incident : le compter mettait l'IMU en ERREUR dès le boot, ce qui rend le voyant inutile. |
| §AF.5 | Étalonnage du BNO085 implicite | Il n'y en avait **aucun** : `sh2_setCalConfig` n'était jamais appelé. Biais accéléromètre de 0,58 m/s² mesuré, cap annoncé à π rad d'incertitude. Activé, avec sauvegarde en flash et pilotage au banc (`tools/imu_cal.py`). |

## AH.2 Ce qui est confirmé sans changement

- Le CAN reste le bus temps réel. La série est un transport de développement, et la §AB.5 énumère tout ce qu'elle ne fournit pas.
- La séparation d'autorité du §G.1 est intacte : le banc ne donne aucune autorité au nœud SAFETY, il ne fait que produire des données.
- Les niveaux N4 et N5 restent matériels et hors du périmètre logiciel.
- Le BNO085 reste sur l'ESP32 en SPI, pour l'horodatage matériel (§G.2).
- `sensor_msgs/Imu` sur `/imu/data` : le §I.2 l'avait déjà retenu, y compris le passage du mode SPI au repli UART-RVC par simple changement de fichier de lancement.

## AH.3 Mesures nouvelles

| # | Mesure | Bloque | Où |
|---|---|---|---|
| **L1** | Aller-retour applicatif de la liaison série | `link.latency_offset_ms`, donc l'horodatage de tous les capteurs | §AG.5 |
| **L2** | Écart type du gyromètre et de l'accéléromètre au repos | Les covariances de `/imu/data`, donc le réglage de l'EKF | §AG.6 |
| **L3** | Norme du champ magnétique à trois distances d'un moteur | Le choix entre `ROTATION_VECTOR` et `GAME_ROTATION_VECTOR` | §AG.9 |

**État des mesures au 20 septembre 2026 :**

| # | Résultat | Statut |
|---|---|---|
| **L1** | Aller-retour médian **3,14 ms**, max 3,88 ms → `latency_offset_ms: 1.57` | ✅ faite, valeur en configuration |
| **L2** | — | ⏳ à faire carte montée. Plancher connu : résolution gyro 1/512 rad/s, donc σ ≥ 0,00056 rad/s |
| **L3** | — | ⏳ à faire carte montée, moteurs alimentés. **Bloque la décision §AF.7** |
| **L4** (nouvelle) | Biais accéléromètre à l'usine : **0,58 m/s²**, `b = (+0,27 ; −0,378 ; −0,34)` | ✅ mesuré ; corrigé par l'étalonnage dynamique, à sauvegarder une fois monté |
| **L5** (nouvelle) | Lidar : 667 points/tour, ~7,5 Hz, **67 % de couverture**, 0,31–5,19 m | ✅ faite, au-dessus du seuil §03 |
| **L6** (nouvelle) | Orientation du lidar : objet à 1 m devant apparaît devant avec `reversion: false`, `inverted: false` | ✅ validée |

## AH.4 La suite, et pourquoi dans cet ordre

```
   B1  IMU → ROS → Foxglove                         ✅ 20 sept. 2026
        │  ce que ça prouve : le protocole, le cadrage, la génération,
        │  les conventions de repères, la chaîne de covariances
        │  → docs/HANDOFF-banc-imu.md
        ▼
   B1' Lidar X4 → ROS → Foxglove                    ✅ 20 sept. 2026
        │  hors socle ESP32 : USB direct, pilote tiers épinglé (.repos).
        │  ce que ça prouve : la méthode — reproduire un témoin qui marche,
        │  puis s'en écarter un paramètre à la fois
        │  → docs/HANDOFF-banc-lidar.md
        ▼
   B2  Deuxième capteur sur le socle ESP32
        │  GPS, ou températures. Coût attendu : une trame dans le YAML,
        │  une tâche, un publisher. Si c'est plus cher que ça, B1 a raté.
        ▼
   B3  ESP32-MOTION : décodage Hall, PCNT, retour de vitesse
        │  toujours en série, roues levées, aucun variateur alimenté
        ▼
   B4  ⚠️ Passage au CAN — dès que safety_bus_distribution existe
        │  §Q niveau 2 EN ENTIER. Rien de la chaîne de sécurité
        │  n'a été validé avant ce point, et rien ne peut l'être avant.
        ▼
   B5  FSM de sécurité, précharge, contacteur
```

⚠️ **B4 ne se place pas « quand la série marchera bien ».** Il se place quand la carte existe. La qualité du banc série ne dit rien sur la chaîne de sécurité, qui n'a pas commencé.

---

*Suite du dossier : `00-index-A-B.md` pour l'index général. Table des trames générée : `generated/protocol-tables.md`.*

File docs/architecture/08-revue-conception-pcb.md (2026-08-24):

# X. Revue de conception des trois PCB — avant schéma

> ## ⚠️ Ce document a été partiellement invalidé — lire d'abord `09` et `11`
>
> Cette revue a été écrite **avant** la validation des composants par datasheet.
> Cinq de ses recommandations sont périmées :
>
> | Dans ce document | À remplacer par | Pourquoi |
> |---|---|---|
> | `SN74LVC14A` | **`SN74LVC3G17`** | TI a retiré la garantie `Ioff` du LVC14A |
> | `2N7002` | **`DMG1012T`** | Non garanti passant sous 3,3 V de grille |
> | `INA226` | **`INA228`** | 36 V de mode commun, inutilisable sur 42 V |
> | `TPS2595` sur le bus 42 V | **`TPS26630`** | Le TPS2595 plafonne à 18 V |
> | Entraxe ESP32 « 22,86 mm » | **25,40 mm** | 22,86 est l'entraxe des cartes tierces 30 broches |
>
> ⚠️ **Et une erreur d'architecture** : le §X.6 suppose, comme le dossier v1.1, que
> tirer `/SAFE` à la masse freine les moteurs. **C'est faux** — cela met les
> variateurs en roue libre et relâche le frein.
> Voir `10-spec-motor-interface.md` §Z.1 et `11-corrections-v1.2.md` §C-S1.
>
> Le raisonnement d'architecture de cette revue reste valable ; ce sont les
> références de composants et la chaîne de freinage qui ont changé.

**Version** : 1.0 — 24 août 2026
**Objet** : audit des deux README existants et du dossier d'architecture v1.1, avant gel des schémas de `motor_interface`, `safety_power` et `can_distribution`.
**Convention de marqueurs** : identique au dossier (`00-index-A-B.md`).

| Marqueur | Signification |
|---|---|
| ✅ **VÉRIFIÉ** | Datasheet constructeur, norme, ou source primaire |
| 🟡 **CONSENSUS** | Rétro-ingénierie communautaire recoupée |
| 🔴 **À MESURER** | Inconnu ou contradictoire — **interdiction de router avant mesure** |
| ⚠️ **RISQUE** | Point dangereux si mal traité |
| 📐 **HYPOTHÈSE** | Valeur que je pose faute de donnée |

---

# X.0 Résumé : ce qu'il faut trancher avant d'ouvrir KiCad

Sept points bloquants. Tant qu'ils ne sont pas tranchés, tout schéma sera à refaire.

| # | Décision | Pourquoi c'est bloquant | Ma recommandation |
|---|---|---|---|
| **D1** | **Le pack est-il un Classic ou un Pro ?** Le README `safety_power` dit `10INR19/66-4` → 10S4P, 474 Wh. Le dossier v1.1 (hypothèse H4) dit 10S3P, 280 Wh. | Change le budget de courant, le calibre de fusible, l'autonomie, et le BMS (donc le protocole UART) | Le marquage `-4` est décisif : c'est un pack **Pro / Pro 2, 37 V, 12800 mAh, 474 Wh** ✅. Le dossier doit être corrigé, pas le README. |
| **D2** | **Contacteur DC ou pas ?** Le README `safety_power` dit « manual isolator, no contactor, précharge sur le loom ». Le dossier fait du contacteur le **niveau 5** de la chaîne de sécurité. | Deux architectures incompatibles. Sans contacteur, il n'existe **aucune coupure matérielle commandable** : le dernier recours redevient un message logiciel — exactement ce que tu voulais éviter. | **Garder le contacteur.** Le README décrit une carte de distribution, pas une carte de sécurité. |
| **D3** | **Fusible de tête 40 A ou 80 A ?** | Le README dit 40 A ; le dossier dit MRBF 80 A. | **80 A.** Voir X.1.2 : un 40 A viole la sélectivité avec les 4 fusibles de branche à 25 A, et fondrait sur un franchissement d'obstacle légitime. Le budget de courant est imposé par l'ESP32-SAFETY, pas par le fusible. |
| **D4** | **`motor_interface` = 4 moteurs ou 2 moteurs ?** Le README décrit une carte 4 moteurs (8 connecteurs, 12 taps, 120 × 79 mm, déjà routée). Ta demande dit « même carte pour traction **ou** propulsion ». | Incompatible. Le dossier prévoit 2 nœuds MOTION × 2 roues. | **2 moteurs par carte, fabriquée en 5 exemplaires** : 2 en service, 3 rechanges universelles. |
| **D5** | **Où passent les signaux de commande VR / DIR / EL / STOP ?** | ⚠️ **Ni l'un ni l'autre des README ne les traite.** `motor_interface` n'a aujourd'hui aucun chemin de commande vers les ZS-X11H. Sans ça, il reste un faisceau volant qui annule l'intérêt de la carte. | Voir X.6.1 — c'est l'omission la plus importante de la revue. |
| **D6** | **`can_distribution` ne distribue-t-il que le CAN ?** | La ligne `/SAFE` traverse les trois cartes et n'est possédée par aucune. | La renommer **`safety_bus_distribution`** : CAN + `/SAFE` + alimentation des nœuds. Voir X.7. |
| **D7** | **Sépare-t-on le porteur MCU de la carte de fonction ?** | C'est la vraie réponse à « matériel générique + lots de 5 ». | Voir X.2 — je présente les deux options honnêtement, la décision t'appartient. |

---

# X.1 Contradictions entre les README et le dossier v1.1

## X.1.1 Identité de la batterie

Le README `safety_power` décode `10INR19/66-4` correctement : 10 cellules série, NMC cylindrique, format 18650, 4 en parallèle. Le contrôle 37 × 12,8 = 473,6 Wh contre 474 Wh sur l'étiquette est concluant.

Le dossier v1.1 (§C.2.1) décrit au contraire un `10INR19/66-3`, 10S3P, 7,8 Ah, 280 Wh — le pack **Classic**.

Les deux packs existent ✅ ; ce sont deux références commerciales différentes. Le `-4` / 474 Wh correspond au **M365 Pro / Pro 2**.

**Conséquences si c'est bien un Pro** :

| Grandeur | Classic (dossier) | Pro (README) | Impact |
|---|---|---|---|
| Énergie | 280 Wh | **474 Wh** | Autonomie ×1,7 |
| Cellules en parallèle | 3 | **4** | Courant admissible ×1,33 → 26–40 A au niveau cellule |
| BMS | STM8L + BQ76930 🟡 | 🔴 **à vérifier** — le BMS Pro n'est pas forcément identique | Le protocole UART §D.9 est à revalider |
| Seuil de coupure | 🔴 non publié | 🔴 non publié | **La mesure M1 reste obligatoire** |

⚠️ **Ne pas déduire le seuil BMS du nombre de cellules.** Le BMS peut très bien limiter au même endroit sur les deux packs. M1 reste bloquante pour `safety_power`.

📐 **Action** : photographier l'étiquette du pack **et** l'étiquette du BMS, puis corriger §C.2.1 du dossier. Cinq minutes, et ça débloque tout le dimensionnement.

## X.1.2 Fusible de tête : pourquoi 80 A et pas 40 A

Le raisonnement du README est séduisant : « une protection qui n'agit jamais avant la chose qu'elle protège est décorative ». Il est juste dans son principe et faux dans son application, parce qu'il confond deux fonctions :

| Fonction | Qui la remplit | Grandeur de dimensionnement |
|---|---|---|
| Empêcher le pack de se décharger trop fort | Le **BMS**, puis le **budget de courant logiciel** (ESP32-SAFETY + ACS758) | 20 A continu 📐 |
| Protéger le **câble de 25 mm²** contre un court-circuit franc | Le **fusible de tête** | Ampacité du câble et I_cc du pack |

Un fusible ne protège pas une batterie : il protège un conducteur. Le 25 mm² admet 92 A après déclassement (§D.6). Le fusible doit se placer sous ce chiffre, au-dessus des pointes légitimes.

**Et surtout, il y a un problème de sélectivité** que ni l'un ni l'autre des documents ne relève :

> Les branches moteur sont protégées par **4 × MIDI 25 A**. Un fusible de tête à 40 A est à **1,6×** le calibre d'une branche. La règle usuelle de sélectivité entre fusibles de même famille est **≥ 2:1**, en pratique 2,5 à 3:1 sur l'I²t de fusion totale.

Conséquence concrète d'un 40 A en tête : sur un court-circuit franc d'un ZS-X11H, **le fusible de tête et le fusible de branche fondent tous les deux**. On perd le robot entier au lieu d'une roue, et on perd surtout l'information de localisation du défaut. Le mode `DEGRADED` sur trois roues décrit au §M.2 devient impossible.

Ajouté à ça : 4 × 20 A de pointe = 80 A est un **franchissement d'obstacle légitime**, pas un défaut. Un 40 A fond en usage normal.

→ **MRBF 80 A / 58 V confirmé.** Le README doit être corrigé sur ce point.

## X.1.3 Le contacteur — la contradiction la plus grave

Le README `safety_power` :

> « The build uses a manual isolator, no contactor. […] It lives on the loom, not on the board. »

Le dossier §A.1-2 :

> « Le dernier niveau capable d'arrêter physiquement les moteurs est le contacteur DC principal, dont la bobine est alimentée à travers le contact NF du champignon. »

Ce ne sont pas deux variantes de la même carte, ce sont deux philosophies. Tu poses toi-même la question dans ta demande :

> « Un système où le dernier recours est uniquement un message CAN n'est pas équivalent à une coupure matérielle de puissance. »

C'est exactement le point. **Sans contacteur, il n'y a plus aucune coupure de puissance commandable** : le champignon ne fait plus que tirer `/SAFE`, c'est-à-dire demander poliment aux ZS-X11H de freiner. Si un MOSFET d'un variateur est collé en conduction — le mode de défaillance le plus courant d'un pont BLDC — `/SAFE` ne fait rien du tout. Seul un fusible qui fond ou une main sur le coupe-batterie arrête le robot.

→ **Le contacteur reste**, et `safety_power` doit l'intégrer : commande de bobine, économiseur PWM, diode de roue libre, temporisation RC ~1 s, relais de précharge, mesure V_pack et V_bus de part et d'autre, détection de contacteur collé (§M.2 panne 31).

## X.1.4 Périmètre de `motor_interface`

Le README décrit une carte 4 moteurs / 8 connecteurs / 12 taps / 1 ESP32, **déjà routée**. Ta nouvelle demande impose une carte générique traction **ou** propulsion, et le dossier §G.2 justifie longuement pourquoi il faut 2 nœuds MOTION de 2 roues et pas 1 nœud de 4.

La carte routée contredit les deux. Elle est aussi le pire des deux mondes : un seul ESP32 pour 4 roues (sa panne immobilise le robot), 8 unités PCNT saturées, et des faisceaux Hall longs qui traversent tout le châssis pour rejoindre une carte unique — alors que le §L4 du dossier insiste pour les garder courts, torsadés et blindés.

→ **2 moteurs par carte.** Le lot de 5 devient : 2 en service (AV, AR), 3 rechanges, et la même carte peut plus tard servir une 5ᵉ/6ᵉ roue, un bras ou une tourelle sans nouveau PCB.

## X.1.5 Le RC du tap Hall : le calcul du README est incomplet

Le README annonce :

> « RC : 1 kR + 10 nF, 10 us, corner near 16 kHz »

C'est vrai **uniquement sur le front descendant**. Sur le front montant, le condensateur est chargé par le pull-up, qui est **dans le ZS-X11H** et de valeur inconnue 🔴 :

```
τ_descente = R_série × C           = 1 k × 10 n  = 10 µs
τ_montée   = (R_pullup + R_série) × C
             si R_pullup = 4,7 k   → 57 µs
             si R_pullup = 10 k    → 110 µs  (t_r 10–90 % ≈ 242 µs)
```

À 110 Hz, une demi-période vaut 4,5 ms, donc 242 µs restent acceptables (5 %). Mais :

1. La constante annoncée est fausse d'un facteur 10 dans le pire cas, et la fréquence de coupure de 16 kHz — précisément celle qui devait rejeter le PWM des variateurs — descend à **1,4 kHz**, soit *en plein* dans la bande du hachage 16–20 kHz. Le filtre ne fait plus le travail qu'on lui demande.
2. L'asymétrie montée/descente introduit un **biais de rapport cyclique** qui se traduit, en décodage quadrature, par une erreur systématique de position par comptage.
3. ⚠️ **Et surtout : si un ZS-X11H est débranché ou mort, sa résistance de pull-up part avec lui.** L'entrée du tampon flotte, oscille, et l'ESP32 compte du bruit. L'odométrie devient fausse — ce qui, comme le note le §M.2 panne 15, est *pire* qu'une odométrie absente.

**Correctif** : mettre le pull-up **sur `motor_interface`**, pas dans le variateur.

```
+5 V_MOT ──[ 2,2 k ]──┬── ligne Hall ──[ 2,2 k ]──┬──[ 10 nF / 100 V ]── GND
                      │                           │
                      │                           ├──[ TVS 5,6 V ]── GND
                 (vers ZS-X11H)                   │
                                                  └──> tampon Schmitt ──> GPIO
```

- 2,2 k vers +5 V en parallèle du pull-up du variateur → τ déterministe (≈ 7 µs), coupure ≈ 22 kHz, et l'entrée ne flotte **jamais**, variateur branché ou non.
- Charge vue par le capteur Hall : 5 V / 2,2 k = 2,3 mA, à comparer aux ~20 mA que sait absorber un Hall à collecteur ouvert 🟡. Confortable.
- Le budget de 30 mA de la sortie logique du ZS-X11H 🔴 n'est pas entamé : les entrées LVC consomment quelques µA.

## X.1.6 Le tampon : famille logique et sens

Le README retient le `SN74LVC14AD` (hex Schmitt **inverseur**). Trois remarques.

**a) La famille LVC est le bon choix, et pour une raison précise qu'il faut écrire.** Les entrées/sorties LVC n'ont **pas de diode de clamp vers V_CC** (fonctionnalité *Ioff* / partial power-down) ✅. C'est exactement ce qui garantit l'exigence dure du README : 3,3 V absent, le tap ne charge pas la ligne Hall, le passthrough survit.

⚠️ **Corollaire à écrire en gras dans la BOM** : ne **jamais** substituer un `74HC14` ou `74HCT14` en cas de rupture de stock. Ces familles ont un clamp vers V_CC : hors tension, elles tirent la ligne Hall vers un rail mort et cassent la garantie.

**b) 12 canaux = 2 × LVC14A exactement, zéro réserve.** Sur une carte 2 moteurs (D4), c'est 6 canaux = 1 boîtier + 0 spare, ou 2 × `SN74LVC3G17` (triple Schmitt **non inverseur**) ✅ si tu veux éviter l'inversion.

**c) L'inversion est acceptable mais doit être documentée**, pas subie. En décodage quadrature, inverser les deux voies conserve le sens (les deux fronts se déplacent ensemble). En décodage 6 états — que je recommande, voir X.6.2 — la table d'états doit être complémentée, et la détection des états interdits `000` / `111` fonctionne toujours (ils s'échangent).

📐 Recommandation : **`SN74LVC3G17` non inverseur** si disponible dans le catalogue de ton assembleur, sinon LVC14A avec un commentaire explicite dans `protocol.h`.
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

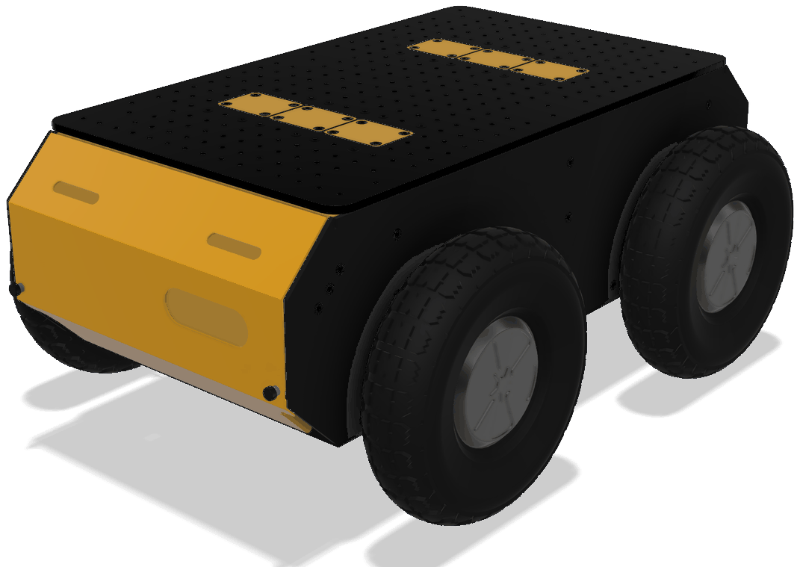
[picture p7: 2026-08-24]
docs/images/cover/02-hero-rear-left.png

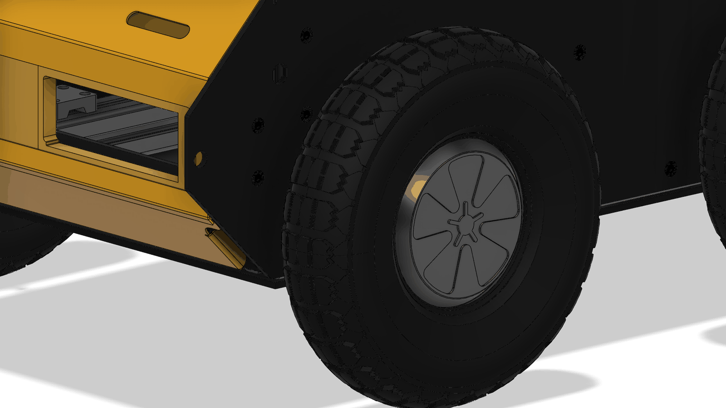
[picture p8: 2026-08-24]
docs/images/cover/12-wheel-mount.png

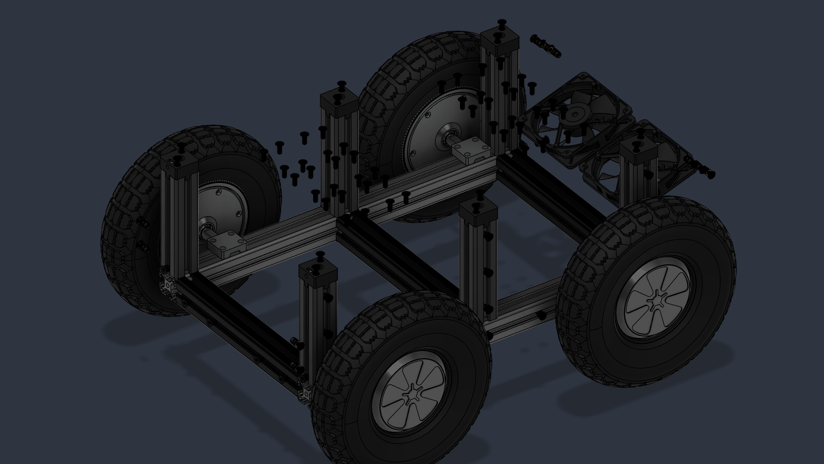
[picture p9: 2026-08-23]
docs/images/16-lower-deck-37v.png

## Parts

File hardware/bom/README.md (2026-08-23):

# Bill of materials

The costed BOM lives in the architecture dossier, section S of
[`docs/architecture/06-bom-fmea-schema-plan.md`](../../docs/architecture/06-bom-fmea-schema-plan.md).

It is split into what is already owned, what must be bought for the robot to be
built safely, what is recommended, and what is optional.

One rule runs through it: where a part could not be verified, the minimum
specification to respect is given instead of a product reference. A
specification stays valid for years; a part number is obsolete in months.

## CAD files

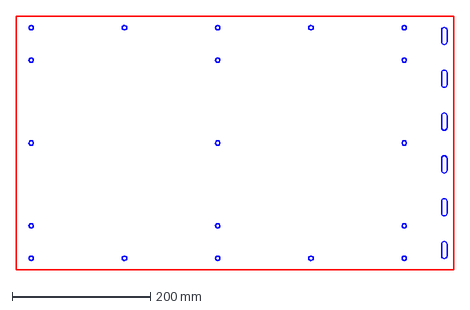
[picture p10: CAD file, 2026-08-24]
hardware/cad/dxf/Plancher.dxf
633.6 x 367.6 mm

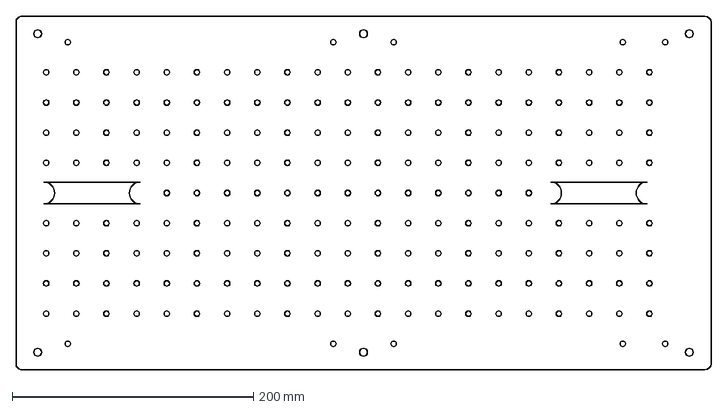
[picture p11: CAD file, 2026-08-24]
hardware/cad/dxf/ETG_Plateau_superieur_PMMA_3mm.dxf
576.0 x 293.0 mm

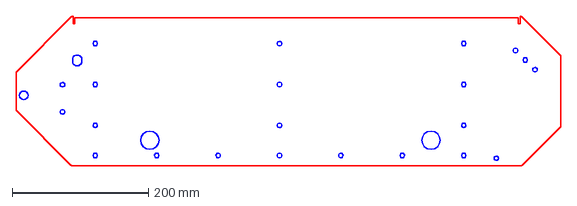
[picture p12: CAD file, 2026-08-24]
hardware/cad/dxf/Panneau_lateral_DROIT.dxf
798.4 x 219.0 mm

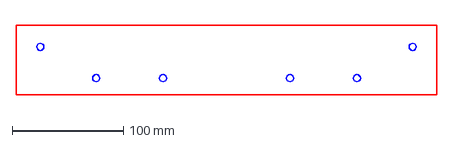
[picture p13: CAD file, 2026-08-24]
hardware/cad/dxf/Panneau_ARRIERE.dxf
377.6 x 62.6 mm

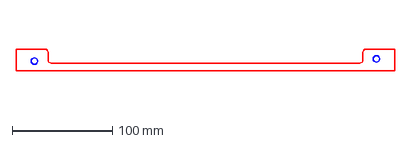
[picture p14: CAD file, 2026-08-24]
hardware/cad/dxf/Panneau_AVANT.dxf
377.6 x 21.8 mm

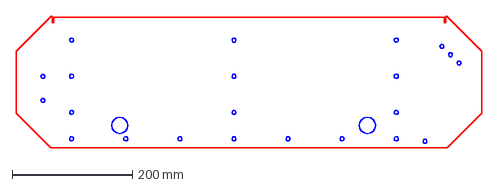
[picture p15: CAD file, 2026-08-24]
hardware/cad/dxf/Panneau_lateral_GAUCHE.dxf
774.7 x 219.0 mm

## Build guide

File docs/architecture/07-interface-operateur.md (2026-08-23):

# W. Interface opérateur — pupitre Nintendo Switch

*Ajout au dossier v1.0 — 10 août 2026. Cette section complète le §O (réseau) et le §L (sécurité) ; elle ne les remplace pas.*

## W.0 Le principe : la Switch ne fait tourner aucun ROS

Ton intuition est la bonne, et elle rejoint exactement l'architecture du §O.1. Je la formalise :

> **Le pupitre est un client léger. Il affiche et il envoie des gestes. Il ne participe pas au graphe ROS 2.**

Trois raisons, dans l'ordre d'importance :

1. **Sécurité.** Un participant DDS de plus sur le Wi-Fi, c'est du trafic de découverte, des retransmissions et une latence non bornée sur le lien radio. §O.1 explique pourquoi le graphe ROS 2 reste confiné à `localhost` sur le X1 : ajouter la Switch au graphe casserait ce choix.
2. **Énergie.** Tu as raison : 16 Wh de batterie, un écran 720p et une pile ROS 2 complète, c'est incompatible avec une session de terrain. Un onglet navigateur consomme une fraction de ce que consomme un `rclcpp` + DDS + RViz.
3. **Faisabilité.** Le noyau de switchroot est un **Linux 4.9.140** (branche L4T r32) ✅ — vérifié dans les sources du noyau. ROS 2 Jazzy cible Ubuntu 24.04 avec un noyau 6.8. Ça se contournerait en conteneur, mais pour quel bénéfice ?

**Conséquence architecturale forte** : le pupitre est **remplaçable et jetable**. N'importe quel appareil avec un navigateur et une manette (PC portable, tablette + manette Bluetooth, Steam Deck) affiche la même interface. La Switch est le pupitre *préféré*, pas le pupitre *requis*. C'est ce qui rend acceptable de bâtir sur une plateforme aussi bricolée.

```
┌─────────────────────────────── SWITCH (client léger) ──────────────────────────┐
│  Joy-Con railés ──► joycon-serdev ──► joycond ──► uinput ──► evdev             │
│                                                                 │              │
│  Firefox ◄──────────────────────────────── Gamepad API ─────────┘              │
│     │                                                                          │
│     │  PWA « Retriever Console » (HTML + JS, ~200 ko, cache service worker)    │
│     │  Canvas 2D lidar · Leaflet carte hors-ligne · <img> MJPEG                │
└─────┼──────────────────────────────────────────────────────────────────────────┘
      │  Wi-Fi
      │  ├── WSS  :443/ws     → rosbridge (télémétrie, commandes, actions Nav2)
      │  ├── HTTPS :443/video → web_video_server (MJPEG)
      │  └── HTTPS :443/      → PWA + tuiles de carte (nginx, statique)
      ▼
┌─────────────────────────────── YOUYEETOO X1 ───────────────────────────────────┐
│  nginx (TLS, auth, reverse-proxy, HTTP/2)                                      │
│    ├─► 127.0.0.1:9090  rosbridge_server        (jamais exposé directement)     │
│    ├─► 127.0.0.1:8080  web_video_server                                        │
│    └─► /var/www/retriever  PWA + tuiles PMTiles                                │
│                                                                                │
│  retriever_teleop_guard  ← LE nœud de sécurité de la téléop (W.5)              │
│  twist_mux · velocity_smoother · Nav2 · … (graphe ROS 2 confiné à localhost)   │
└────────────────────────────────────────────────────────────────────────────────┘
```

---

## W.1 Ce que la Switch peut réellement faire — état vérifié

### La plateforme

| Élément | Fait | Confiance |
|---|---|---|
| Distributions switchroot | Ubuntu **Noble 24.04** (Kubuntu ou Unity), Jammy 22.04, Bionic 18.04, Fedora 42. **Pas de Focal.** | ✅ wiki officiel |
| Projet vivant en 2026 | Image Noble `2026-05-13` déposée le `2026-07-30` sur `download.switchroot.org` | ✅ listing serveur |
| **Noyau** | **Linux 4.9.140** (L4T r32.7.x). ⚠️ Les « 5.1.2 / 6.0.0 » du changelog sont des **versions d'image**, pas de noyau — piège classique | ✅ vérifié dans les sources |
| SoC | Tegra X1 T210 (2017) ou T210B01 « Mariko » (2019/Lite/OLED), 4× Cortex-A57, GPU Maxwell 256 cœurs, **4 Go LPDDR4** | ✅ |
| Écran portable | **720p @ 60 Hz** | ✅ |
| Batterie | **16,0 Wh** (HAC-003) · Lite : 13,2 Wh | ✅ iFixit |
| Autonomie sous switchroot | 🔴 **NON PUBLIÉE** — aucun chiffre sourcé n'existe | — |
| Modchip | Switch 2019 / Lite / OLED **exigent un modchip** ; seule la 2017 « Erista » se lance par RCM | ✅ |
| Switch 2 | ❌ **Non supportée, aucune perspective** | 🟡 consensus |

### ⚠️ Piège n°1 — Chromium est figé et Firefox est obligatoire

Deux faits indépendants qui pointent dans la même direction :

- **Le Chromium de switchroot est bloqué à la version 126** (mi-2024) et son dépôt de build est marqué *DEPRECATED* ✅. Pour un pupitre destiné à durer, c'est un navigateur qui ne recevra **plus jamais de correctif de sécurité**.
- **Chromium ne verra probablement pas tes Joy-Con.** Son `RefreshJoydevDevice()` écarte du chemin joydev tout périphérique dont le VID:PID figure dans `IsNintendoController()` — ce qui inclut `057e:2006` et `057e:2007`, exactement les PID des Joy-Con railés ✅ (vérifié dans les sources Chromium). Il les délègue au `NintendoDataFetcher`, qui énumère via **hidraw**… or le pilote `joycon-serdev` **ne crée aucun nœud hidraw**. Résultat attendu : invisibles.

→ **Firefox, depuis le PPA `mozillateam`** (maintenu, avec accélération vidéo Tegra). Bonus : son backend evdev applique le mapping « standard » dès qu'il voit `BTN_SOUTH`, ce que le périphérique combiné de joycond expose — là où Chromium le classerait `kUnknownGamepad` avec un mapping vide.

### ⚠️ Piège n°2 — Firefox exige un contexte sécurisé pour l'API Gamepad

**Depuis Firefox 81, `navigator.getGamepads()` renvoie un tableau vide en contexte non sécurisé** ✅. Une IHM servie en `http://192.168.4.1/` ne verra **aucune manette**.

Deux solutions, et je recommande la première :

| Solution | Comment | Compromis |
|---|---|---|
| ✅ **HTTPS depuis le robot** | nginx + certificat auto-signé de longue durée (10 ans), importé **une fois** dans le magasin de confiance de Firefox sur la Switch | Une manipulation à l'installation, puis on n'y pense plus. Une seule source de vérité pour l'IHM. |
| 🟡 IHM hébergée sur la Switch | Un serveur statique local ; `http://localhost` **est** un contexte sécurisé par définition | Le code de l'IHM est dupliqué sur chaque pupitre, à resynchroniser à chaque mise à jour |

Le certificat auto-signé sert aussi au **WSS** : rosbridge n'a **aucune authentification** (voir W.4), le chiffrement et l'authentification sont entièrement à la charge de nginx.

### ⚠️ Piège n°3 — les sticks pilotent le curseur de la souris

switchroot livre par défaut `/usr/share/X11/xorg.conf.d/50-joystick.conf` (xf86-input-joystick) : **bouger un stick déplace le pointeur** et des boutons émettent des touches ✅. Pour un pupitre, c'est ingérable. → Vider ou supprimer ce fichier à l'installation.

### ⚠️ Piège n°4 — les Joy-Con railés sont **deux** périphériques

En mode portable, ils ne passent pas par `hid-nintendo` (le driver Bluetooth/USB mainline) mais par un pilote **serdev/UART** propre à switchroot, `drivers/input/joystick/joycon-serdev.c` ✅ :

| Périphérique | VID:PID | Axes | Boutons |
|---|---|---|---|
| `Nintendo Switch Left Joy-Con Serial` | `057e:2006` | `ABS_X`, `ABS_Y` | `SELECT, Z, THUMBL, DPAD_*, TL, TL2` |
| `Nintendo Switch Right Joy-Con Serial` | `057e:2007` | `ABS_RX`, `ABS_RY` | `START, MODE, THUMBR, SOUTH/EAST/NORTH/WEST, TR, TR2` |

**`joycond` est indispensable** pour les fusionner en un `Nintendo Switch Combined Joy-Cons` (`057e:2008`, bus virtuel, uinput) qui expose les 4 axes et le jeu de boutons complet. Le fork switchroot (`CTCaer/joycond`) détecte le cas rail et accepte l'appairage en permanence.

⚠️ **Mais la fusion n'est déclenchée que par un événement evdev** : il faut **appuyer sur L+R (ou ZL+ZR) après chaque démarrage** pour que la manette combinée apparaisse. Ce n'est pas un bug, c'est le fonctionnement de joycond — et ça doit figurer dans la procédure de mise en route, et être diagnostiqué par l'IHM (W.6).

⚠️ **Pas de gyroscope sur les Joy-Con railés.** Le périphérique IMU n'est instancié que pour le pad intégré de la Switch **Lite** ✅ (vérifié dans le code — le wiki affirme le contraire, mais son affirmation vaut pour le chemin Bluetooth). L'IMU de la console elle-même reste accessible en **IIO** (`/sys/bus/iio/devices/`), pas en evdev. Sans conséquence : je ne recommande pas de piloter un robot de 35 kg à l'inclinaison du pupitre.

### ⚠️ Piège n°5 — la dérive des sticks, et c'est le vrai danger

Le noyau applique une zone morte de `flat = 1500` sur une plage de `±32767`, soit **4,6 %** ✅. C'est très insuffisant pour un Joy-Con usagé.

**Un stick qui dérive, c'est une consigne de vitesse non nulle au repos.** C'est le risque n°1 de tout ce chapitre, et il est aggravé par le fait que la dérive des Joy-Con est un défaut d'usure documenté à l'échelle du produit (recours collectifs, excuses publiques de Nintendo) 🟡.

Trois parades cumulatives, détaillées en W.3 et W.5 : **zone morte applicative de 15 %**, **homme-mort obligatoire**, et **test de repos au moment de l'armement**.

---

## W.2 Choix de la pile logicielle

### Le pont : `rosbridge_server`, pas `foxglove_bridge`

| Critère | `foxglove_bridge` 3.4.1 ✅ | `rosbridge_server` 2.7.0 ✅ |
|---|---|---|
| Présent en apt Jazzy (arm64 + amd64) | ✅ | ✅ |
| Langage / coût CPU | C++, relais CDR **sans sérialisation** — le moins cher | Python, CDR→objets→JSON — plus cher |
| Publication depuis le client | ✅ `clientPublish` + `client_topic_whitelist` | ✅ `advertise`/`publish` + `topics_pub_glob` (nouveau en 2.7.0) |
| **Actions ROS 2** | ❌ services seulement | ✅ **`send_action_goal` / `cancel_action_goal` / `action_feedback` / `action_result`** |
| Client JS | Il faut désérialiser le CDR soi-même | ✅ **`roslib` 2.1.0** (2026-03, réécrit en TypeScript/ESM, maintenu) |
| Compression | Aucune dans le protocole | `cbor`, `cbor-raw` (= volume CDR), `throttle_rate` par abonnement |
| TLS natif | ✅ | ✅ (mais on passe par nginx de toute façon) |
| Authentification | ❌ | ❌ (`rosauth` n'existe pas pour Jazzy ✅) |
| Maintenance amont | Actif | ✅ **Très actif** : 2.7.0 le 2026-05-27, backports systématiques |

**Le facteur décisif, ce sont les actions.** Tu veux des missions par waypoints GPS : ça veut dire appeler `nav2_msgs/action/NavigateToPose` et `FollowGPSWaypoints`, suivre leur *feedback* et pouvoir les annuler. Seul rosbridge parle nativement les actions ROS 2. Avec foxglove_bridge, il faudrait écrire un nœud passerelle action↔service — du travail pour rien.

Le surcoût CPU de rosbridge est réel mais mesurable et maîtrisable : voir W.4.

### Le client : une PWA maison, pas Foxglove Studio

**Foxglove Studio n'est plus utilisable dans ce contexte** ✅ :
- Le viewer **n'est plus open source** (dernière release ouverte : v1.x, février 2024 ; dépôt archivé).
- **Pas de version web auto-hébergeable**, et une connexion au cloud est requise au moins une fois. L'usage totalement hors-ligne relève d'une **licence commerciale sur devis**.

Le *pont* Foxglove reste sous licence MIT et excellent — c'est le client qui pose problème.

Deux alternatives évaluées :

| Option | Verdict |
|---|---|
| **Lichtblick** (fork MPL-2.0 du dernier Studio ouvert, v1.26.0 du 2026-06-17, tourne en Docker dans le navigateur, sans login) | ✅ **À garder pour le diagnostic à l'atelier.** C'est un excellent outil de debug. Mais c'est un outil généraliste lourd, pas une console de conduite : rien n'y est pensé pour une manette et un écran 720p tenu à bout de bras. |
| **PWA maison** | ✅ **Retenu pour le pupitre.** ~200 ko de HTML/JS, exactement les fonctions voulues, mapping Joy-Con sur mesure, logique d'homme-mort maîtrisée. |

### Les briques, toutes vérifiées présentes en apt Jazzy arm64 ✅

| Paquet | Version | Rôle |
|---|---|---|
| `ros-jazzy-rosbridge-server` | 2.7.0 | Pont WebSocket |
| `ros-jazzy-rosapi` | 2.7.0 | Introspection |
| `ros-jazzy-web-video-server` | 3.1.0 | MJPEG / VP8 / H264 |
| `ros-jazzy-compressed-image-transport` | 4.0.7 | JPEG côté ROS |
| `ros-jazzy-twist-mux` | 4.5.0 | Priorités + **timeouts** |
| `ros-jazzy-nav2-velocity-smoother` | 1.3.12 | Rampe d'arrêt |
| `ros-jazzy-tf2-web-republisher` | 1.0.0 | TF pour clients web |
| `nginx` (Ubuntu noble) | 1.24.0 | TLS, auth, reverse-proxy, HTTP/2 |

Côté navigateur : `roslib` **2.1.0**, `leaflet` **1.9.4**, `pmtiles` **4.4.1**. Le rendu lidar et carte d'occupation est **fait maison en Canvas 2D** — `ros2djs` et `ros3djs` sont morts (dernière publication **2022-05-03**, et `ros3djs` épingle `three@0.89` alors que Three.js en est à 0.185) ✅.

---

## W.3 Cartographie des Joy-Con

Le périphérique combiné de joycond expose `BTN_SOUTH`, donc **Firefox annonce `mapping: "standard"`** ✅ et les index sont ceux de la spécification W3C.

```
        ┌─ Joy-Con GAUCHE ─┐                  ┌─ Joy-Con DROIT ─┐
        │                  │                  │                 │
   ZL ══╡ HOMME-MORT       │                  │      VITESSE ++ ╞══ ZR
    L ──┤ vitesse max −    │                  │  vitesse max +  ├── R
        │                  │                  │                 │
        │   ╭───╮          │                  │        (X)      │
        │   │ ↑ │ stick G  │                  │    (Y)   (A)    │
        │   ╰───╯ AVANT/   │                  │        (B)      │
        │        ARRIÈRE   │                  │                 │
        │                  │                  │   ╭───╮         │
        │  ▲               │                  │   │↔ │ stick D  │
        │ ◄ ►  croix       │                  │   ╰───╯ ROTATION│
        │  ▼               │                  │                 │
        │      (−)         │                  │      (+)        │
        └──────────────────┘                  └─────────────────┘
```

| Contrôle | Index W3C | Fonction | Sécurité |
|---|---|---|---|
| **ZL** | bouton 6 | **HOMME-MORT — maintenu** | ⚠️ Aucun `Twist` non nul n'est émis sans lui |
| **Stick gauche, axe Y** | axe 1 | `linear.x` | Zone morte 15 %, courbe quadratique |
| **Stick droit, axe X** | axe 2 | `angular.z` | idem |
| ZR | bouton 7 | Vitesse haute *tant que ZL est tenu* | Plafond relevé, jamais au-delà de la limite firmware |
| L / R | boutons 4 / 5 | Plafond de vitesse − / + (5 crans) | Persistant |
| **B** | bouton 0 | **ARRÊT** — arrêt opérationnel + désarmement | ⚠️ **Ce n'est PAS un arrêt d'urgence** (W.5.6) |
| A (appui long 1 s) | bouton 1 | Demande d'armement | Appui long volontaire |
| X | bouton 3 | Cycle d'affichage : CONDUITE → CAPTEURS → CARTE → DIAG | |
| Y | bouton 2 | Poser un waypoint / marquer un point d'intérêt | |
| Croix | boutons 12–15 | Navigation dans l'IHM, sélection de waypoint | |
| − | bouton 8 | Désarmement | |
| + | bouton 9 | Menu / paramètres | |
| Clic stick G / D | boutons 10 / 11 | Recentrer la vue / basculer la caméra | |

**Schéma « twin-stick » et non « single-stick »** : l'avance est sur un stick, la rotation sur l'autre. Sur un skid-steer, un seul stick pour les deux couple avance et rotation à chaque micro-mouvement du pouce, et une dérive diagonale devient une trajectoire en arc. Deux sticks séparent les fautes.

### Traitement du signal des sticks

```js
const DEADZONE = 0.15;        // 15 %, très au-delà des 4,6 % du noyau
const EXPO     = 2.0;         // courbe quadratique : finesse au centre

function shapeAxis(v) {
  const a = Math.abs(v);
  if (a < DEADZONE) return 0;                       // zone morte franche
  const n = (a - DEADZONE) / (1 - DEADZONE);        // renormalisation
  return Math.sign(v) * Math.pow(n, EXPO);          // expo
}
```

⚠️ **La renormalisation après zone morte n'est pas cosmétique** : sans elle, la commande saute brutalement de 0 à 15 % dès qu'on sort de la zone morte. Avec, la sortie est continue.

⚠️ **Test de repos à l'armement** (parade n°3 contre la dérive) : au moment où l'opérateur demande l'armement, l'IHM vérifie que **les quatre axes lisent moins de 5 % pendant 1 seconde continue**. Sinon : refus, et message explicite *« Stick gauche à 11 % au repos — dérive détectée, armement refusé »*. Cela transforme une panne silencieuse et dangereuse en un message clair.

---

## W.4 Protocole et budget de bande passante

### Topics exposés au client

| Sens | Topic | Type | Cadence | Encodage |
|---|---|---|---|---|
| ↑ client → robot | `/web/cmd_vel` | `geometry_msgs/Twist` | **20 Hz fixe** | JSON (22 kbit/s, négligeable) |
| ↑ | `/web/heartbeat` | `retriever_msgs/WebHeartbeat` (seq + timestamp client) | **10 Hz** | JSON |
| ↑ | `/web/estop_request` | `std_msgs/Bool` | événementiel | JSON |
| ↓ robot → client | `/web/link_status` | `retriever_msgs/LinkStatus` (dernier seq reçu, état) | 5 Hz | JSON |
| ↓ | `/retriever/safety_state` | custom | 10 Hz *(décimé depuis 100 Hz)* | JSON |
| ↓ | `/retriever/telemetry` | `std_msgs/Float32MultiArray` | 10 Hz | JSON |
| ↓ | `/battery_state` | `sensor_msgs/BatteryState` | 1 Hz | JSON |
| ↓ | `/diagnostics_agg` | `diagnostic_msgs/…` | 1 Hz | JSON |
| ↓ | `/scan` | `sensor_msgs/LaserScan` | 7 Hz | **`cbor-raw`** |
| ↓ | `/map` | `nav_msgs/OccupancyGrid` | à la demande | `cbor` |
| ↓ | `/gps/fix` | `sensor_msgs/NavSatFix` | 1 Hz | JSON |
| ↓ | `/odometry/filtered/global` | `nav_msgs/Odometry` | 5 Hz *(décimé)* | JSON |
| ↔ actions | `NavigateToPose`, `FollowGPSWaypoints` | Nav2 | événementiel | JSON |
| ↓ vidéo | hors WebSocket | MJPEG via `web_video_server` | 10 fps | HTTP |

### Budget, chiffré

Chiffres calculés, pas estimés (sérialisation réelle) :

| Flux | Débit |
|---|---|
| Lidar X4 (714 pts/scan à 7 Hz), CDR / `cbor-raw` | **163 kbit/s** |
| *— le même en JSON brut* | *788 kbit/s (**×4,8**)* |
| *— en JSON arrondi à 3 décimales* | *294 kbit/s* |
| MJPEG 640×480 @ 10 fps, **q = 70** | **1 682 kbit/s** |
| *— le même à q = 95 (défaut de `web_video_server` ⚠️)* | *~4 000 kbit/s* |
| Télémétrie en `Float32MultiArray` @ 10 Hz | **72 kbit/s** |
| *— la même en JSON à champs nommés* | *172 kbit/s (**×2,4**)* |
| `cmd_vel` @ 20 Hz | 22 kbit/s |
| **Total configuration frugale** | **≈ 1,9 Mbit/s** |
| Total configuration naïve (JSON partout, q = 95, 15 fps) | ≈ 7,8 Mbit/s |

Trois enseignements concrets :

1. ⚠️ **`web_video_server` a `quality=95` par défaut** — descendre à 70 divise le débit par 2,4 pour une différence visuelle négligeable sur un écran 720p.
2. ⚠️ **Ne publier `intensities` que si le capteur en produit.** Le YDLIDAR X4 n'en produit pas ; certains drivers remplissent quand même le tableau de zéros, ce qui **double** le débit pour rien.
3. **Une image brute ne doit jamais transiter.** Un `sensor_msgs/Image` 640×480 `rgb8` à 10 fps, c'est **73,7 Mbit/s**. Toujours `default_transport=compressed`.

Un Wi-Fi 802.11n 2,4 GHz réel donne 15–30 Mbit/s en conditions moyennes mais **s'effondre en bord de couverture**. La configuration frugale garde une marge ×8. Prévoir malgré tout une **dégradation adaptative** : au-delà d'un RTT seuil, l'IHM réduit d'abord le débit d'images, puis coupe la vidéo, puis coupe le lidar — la télémétrie et l'homme-mort passent en dernier.

### Sécurisation du transport

⚠️ **rosbridge sur ROS 2 Jazzy n'a aucune authentification** ✅ (le paquet `rosauth` n'existe pas pour Jazzy, l'opcode `auth` a disparu du protocole v2). **Quiconque atteint le port 9090 pilote le robot.**

```
rosbridge_server        → écoute sur 127.0.0.1:9090 UNIQUEMENT
web_video_server        → écoute sur 127.0.0.1:8080 UNIQUEMENT
nginx :443 (TLS, HTTP/2)
   ├── /             → /var/www/retriever            (PWA + tuiles PMTiles)
   ├── /ws           → proxy_pass 127.0.0.1:9090 (WebSocket upgrade)
   └── /video/       → proxy_pass 127.0.0.1:8080
   auth_basic + client cert optionnel ; rate limiting
```

Garde-fous à activer côté rosbridge, tous vérifiés existants :

```yaml
rosbridge_websocket:
  ros__parameters:
    port: 9090
    address: "127.0.0.1"
    topics_pub_glob: ["/web/cmd_vel", "/web/heartbeat", "/web/estop_request"]  # ← 2.7.0
    topics_sub_glob: ["/retriever/*", "/scan", "/map", "/gps/fix", "/battery_state",
                      "/diagnostics_agg", "/odometry/filtered/global", "/web/link_status"]
    services_glob:  ["/retriever/arm", "/retriever/disarm", "/retriever/clear_fault"]
    actions_glob:   ["/navigate_to_pose", "/follow_gps_waypoints"]
    websocket_ping_interval: 2.0     # ⚠️ défaut 0.0 = DÉSACTIVÉ
    websocket_ping_timeout: 6.0
    use_events_executor: true        # réduit la conso CPU au repos (2.5.0+)
    max_message_size: 1000000
```

⚠️ **`topics_pub_glob` est la ligne la plus importante de ce fichier.** Sans elle, un client web peut publier sur `/diff_drive_controller/cmd_vel` et court-circuiter `twist_mux`, le collision monitor et toute la chaîne de filtres du §L.2. Avec elle, le seul chemin de commande est celui qui passe par le superviseur.

⚠️ Le `websocket_ping_interval` est à **0.0 par défaut**, c'est-à-dire désactivé. Mais attention : le ping WebSocket est traité par la pile Tornado et **ne prouve pas que la boucle ROS tourne**. Il ne remplace pas le heartbeat applicatif de W.5.

### Réseau de terrain

Le §O prévoit WireGuard. ⚠️ **Sur le noyau 4.9 de switchroot, le module WireGuard n'est pas intégré** (il l'est depuis Linux 5.6) — il faudrait un module DKMS ou une implémentation en espace utilisateur. 🔴 **À vérifier avant de s'engager.**

Pour l'usage de terrain, ce n'est pas bloquant : le VPN du §O sert à traverser Internet, ce qui n'est pas le cas ici. Sur le terrain, la configuration est plus simple et tout aussi sûre :

| Mode | Configuration |
|---|---|
| **TERRAIN** | Le robot est **point d'accès Wi-Fi** (WPA2/WPA3, réseau isolé, pas de route vers Internet). La Switch s'y connecte. nginx en TLS + auth Basic. Pas de VPN. |
| **ATELIER** | Les deux sur le réseau local ou en Ethernet. Idem. |
| **DISTANT** (par Internet) | WireGuard **obligatoire**, conformément au §O — et depuis un client qui le supporte (PC portable), pas depuis la Switch tant que le point ci-dessus n'est pas tranché. |

⚠️ Bug connu : sur switchroot **KDE Plasma**, la connexion échoue sur les réseaux en **mode transition WPA3/WPA2** ✅. Contournement : `nmcli dev wifi connect <SSID>`, ou forcer le point d'accès du robot en WPA2 seul.

---

## W.5 Sécurité de la téléopération — la partie qui compte

### W.5.1 Le principe

> **Le pupitre est la partie la moins fiable de tout le robot.** Chromium figé, noyau 4.9, sticks qui dérivent, batterie non caractérisée, lien radio. L'architecture doit donc garantir que **sa défaillance est sans conséquence** — et non espérer qu'il ne défaille pas.

C'est déjà vrai par construction : le pupitre n'est qu'une source de `cmd_vel` parmi d'autres, filtrée par les sept étages du §L.2 et arbitrée par `twist_mux`. La présente section ajoute la couche qui manquait : **la détection de perte de lien**.

### W.5.2 Les sept couches

```
┌─ ① HOMME-MORT (client) ────────────────────────────────────────────────┐
│  ZL maintenu. Aucun Twist non nul émis sans lui.                       │
│  ⚠️ Relâchement FORCÉ sur : visibilitychange, blur, gamepad            │
│     disconnect, page masquée, onglet en arrière-plan.                  │
├─ ② PUBLICATION CADENCÉE (client) ───────────────────────────────────────┤
│  20 Hz FIXE tant que ZL est tenu — jamais « seulement quand ça change ».│
│  Un message perdu ne doit pas figer la consigne.                        │
├─ ③ HEARTBEAT BIDIRECTIONNEL ────────────────────────────────────────────┤
│  ↑ /web/heartbeat 10 Hz : compteur de séquence + horodatage client      │
│  ↓ /web/link_status 5 Hz : dernier seq reçu + état du superviseur       │
│  Le client calcule le RTT, affiche la dégradation, et RELÂCHE           │
│  L'HOMME-MORT DE LUI-MÊME au-delà du seuil.                             │
├─ ④ ANTI-REJEU ──────────────────────────────────────────────────────────┤
│  Le superviseur rejette tout seq non strictement croissant.             │
│  ⚠️ Ce n'est PAS de la sécurité cryptographique — c'est WSS qui l'assure.│
├─ ⑤ TIMEOUT twist_mux ───────────────────────────────────────────────────┤
│  timeout: 0.3 s sur l'entrée web (≈6 périodes à 20 Hz).                 │
│  Au-delà : la voie web est ignorée, vitesse 0 substituée.               │
├─ ⑥ SUPERVISEUR retriever_teleop_guard (ROS 2) ──────────────────────────┤
│  Surveille l'âge du heartbeat ET du dernier Twist.                      │
│  Dépassement → verrou twist_mux priorité 255 → arrêt EN RAMPE via       │
│  velocity_smoother (pas un zéro brutal : ça fait déraper ou basculer).  │
│  ⚠️ INHIBE LE REDÉMARRAGE AUTOMATIQUE au retour du lien.                │
├─ ⑦ CHAÎNE MATÉRIELLE (§L) ──────────────────────────────────────────────┤
│  Champignon → /SAFE → contacteur. Indépendante de tout ce qui précède.  │
└─────────────────────────────────────────────────────────────────────────┘
```

Configuration `twist_mux` correspondante :

```yaml
twist_mux:
  ros__parameters:
    topics:
      web_teleop:  {topic: /web/cmd_vel, timeout: 0.3, priority: 100}
      navigation:  {topic: /cmd_vel_nav, timeout: 0.5, priority: 10}
    locks:
      teleop_guard: {topic: /web/link_lost, timeout: 0.0, priority: 254}
      estop:        {topic: /retriever/estop_active, timeout: 0.0, priority: 255}
```

### W.5.3 `retriever_teleop_guard` — nouveau nœud, à ajouter au §I

| | |
|---|---|
| **Responsabilité** | Surveiller la vivacité du pupitre. Verrouiller `twist_mux` en cas de perte. Interdire le redémarrage automatique. |
| **Publie** | `/web/link_lost` (`std_msgs/Bool`, verrou) · `/web/link_status` (5 Hz) · `/diagnostics` |
| **Souscrit** | `/web/heartbeat` · `/web/cmd_vel` · `/retriever/safety_state` |
| **Services** | `/web/rearm` (réarmement explicite après une perte) |
| **Paramètres** | `heartbeat_timeout: 0.5` · `cmd_timeout: 0.3` · `require_explicit_rearm: true` · `ramp_down_time: 0.8` |
| **Fréquence** | 50 Hz |
| **Criticité** | **C2** |

⚠️ **`require_explicit_rearm: true` n'est pas négociable.** C'est l'esprit de la clause **ISO 3691-4 §4.1.14 « Avoidance of automatic restart »** ✅ (clause vérifiée dans la table des matières publique). Concrètement : quand le Wi-Fi revient après une coupure, le robot **ne repart pas tout seul**. L'opérateur voit un bandeau « LIEN RÉTABLI — réarmement requis » et doit appuyer sur A pendant une seconde. Un robot qui redémarre seul dès que la connexion revient, alors que l'opérateur a peut-être posé le pupitre et s'est approché du robot, est un accident qui attend son heure.

### W.5.4 Budget de latence

```
t_total = t_détection_client + t_transit_radio + t_file_WS + t_ROS + t_freinage
```

| Étape | Valeur 📐 | Origine |
|---|---|---|
| Détection côté client (5 heartbeats manqués à 10 Hz) | 500 ms | choix de conception |
| Transit radio, Wi-Fi dégradé | 20–200 ms | mesuré au banc |
| Timeout `twist_mux` | 300 ms | paramètre |
| Boucle superviseur (50 Hz) | 20 ms | |
| Rampe d'arrêt `velocity_smoother` | 800 ms | paramètre |
| **Total, cas défavorable** | **≈ 1,8 s** | |

Rapporté à **ISO 13855:2024** ✅, dont la vitesse d'approche de référence est 1600 mm/s pour des temps d'arrêt > 500 ms, et qui donne le rapport direct **150 ms de temps d'arrêt supplémentaire = 300 mm de distance de sécurité en plus** :

> À 0,5 m/s, 1,8 s de détection et d'arrêt = **90 cm parcourus**.

📐 C'est acceptable en terrain dégagé et sans tiers. Ça ne l'est pas dans un couloir ou près de quelqu'un. **Deux conséquences directes** :

- La vitesse maximale en téléopération Wi-Fi est plafonnée à **0,8 m/s** 📐, pas 1,5 m/s. Le plafond nominal ne s'applique qu'en mission autonome, où le `collision_monitor` réagit localement en ~100 ms.
- Le `collision_monitor` (§I.2) reste actif **y compris en téléopération** — il s'interpose entre `twist_mux` et le contrôleur. L'opérateur ne peut pas conduire dans un obstacle même en tenant l'homme-mort.

### W.5.5 Ce qui manque, et qu'il faut acheter

⚠️ **Avec la téléopération, l'arrêt d'urgence radio passe de « recommandé » à quasi obligatoire.**

Le raisonnement est simple : le champignon du §L est **sur le robot**. En téléopération, l'opérateur est à 10 ou 30 m, une manette dans les mains. Si le robot part de travers, il ne peut pas atteindre le champignon. Le bouton B de l'IHM traverse le navigateur, le Wi-Fi, nginx, rosbridge et Python — ce n'est pas un arrêt d'urgence.

→ **Un e-stop radio à contact NF, inséré en série dans la boucle matérielle existante** (§D.3-④). Il ne dépend d'aucun logiciel, et son récepteur relâche la bobine du contacteur exactement comme le champignon. ~90 €, déjà listé au §S.3 ; je le remonte en priorité impérative dès que la téléopération est en service.

### W.5.6 Vocabulaire — un point qui n'est pas cosmétique

| Ce qu'on appelle | Ce que c'est vraiment | Étiquette dans l'IHM |
|---|---|---|
| Champignon sur le robot | **Arrêt d'urgence** (ISO 13850, catégorie 0/1, matériel) | — |
| E-stop radio | **Arrêt d'urgence** (matériel) | — |
| Bouton B / bouton rouge de l'IHM | **Arrêt opérationnel** (catégorie 2, logiciel) | **« ARRÊT »**, jamais « arrêt d'urgence » |
| Relâchement de l'homme-mort | Arrêt de la commande | — |

**La norme directement applicable ici est IEC 62745:2017** *« Safety of machinery — Requirements for cableless control systems »* 🟡 (texte payant, non lu). Ses principes rapportés : la perte de communication est traitée comme **un défaut dangereux** exigeant une transition automatique vers un état sûr, avec heartbeat, validation de séquence, CRC et watchdogs — c'est exactement l'architecture ci-dessus. Et : *« wireless does not reduce the safety requirements »*.

Si le robot devait un jour être certifié, c'est cette norme-là qu'il faut acheter (~200 €), pas ISO 10218.

---

## W.6 Maquette d'écran

Écran 720p (1280 × 720), tenu à bout de bras, en extérieur, parfois au soleil. → **gros caractères, fort contraste, très peu d'éléments, aucune information décorative.**

### Mode CONDUITE (par défaut)

```
┌────────────────────────────────────────────────────────────────────────────┐
│ ● ARMÉ         Wi-Fi ▊▊▊▊▁  RTT 34 ms      🔋 72 %  36,8 V  −4,2 A   14:23 │ ← bandeau d'état
├────────────────────────────────────────────────────────────────────────────┤
│                                                     ┌────────────────────┐ │
│                                                     │                    │ │
│                   FLUX CAMÉRA                       │   ╱─────────╲      │ │
│                   640 × 480 · 10 fps                │  │   LIDAR   │     │ │
│                                                     │  │     ▲     │     │ │
│                                                     │   ╲─────────╱      │ │
│                                                     │  portée 5 m        │ │
│                                                     └────────────────────┘ │
│                                                     ┌────────────────────┐ │
│                                                     │ VITESSE            │ │
│                                                     │   0,42 m/s         │ │
│                                                     │   ██████░░░░  plaf.│ │
│                                                     │   0,8 m/s (cran 3) │ │
│                                                     └────────────────────┘ │
├────────────────────────────────────────────────────────────────────────────┤
│  ╔══════════════════════════════════════════════════════════════════════╗  │
│  ║   ZL MAINTENU — CONDUITE ACTIVE                                      ║  │ ← bandeau homme-mort
│  ╚══════════════════════════════════════════════════════════════════════╝  │   vert plein si tenu
│  4 roues ✔   IMU ✔   GPS 9 sat ✔   Lidar ✔   T° 41 °C   ⚠ Kinect absent   │   gris barré sinon
└────────────────────────────────────────────────────────────────────────────┘
```

Le bandeau d'homme-mort occupe toute la largeur et change de couleur de façon massive : **vert plein** quand ZL est tenu, **gris rayé** sinon, **rouge clignotant** en cas de perte de lien. C'est l'élément que l'opérateur voit du coin de l'œil sans quitter la scène des yeux.

### États du bandeau supérieur

| État | Fond | Texte |
|---|---|---|
| `SAFE` / `READY` | gris | ● PRÊT |
| `ARMED` | bleu | ● ARMÉ |
| `RUNNING` | vert | ● MISSION EN COURS |
| `DEGRADED` | orange | ▲ DÉGRADÉ — *cause* |
| `FAULT` | rouge | ■ DÉFAUT — *cause* |
| `ESTOP` | rouge clignotant | ✖ ARRÊT D'URGENCE |
| Lien perdu | rouge rayé | ✖ LIEN PERDU — réarmement requis |

### Mode CARTE (missions)

```
┌────────────────────────────────────────────────────────────────────────────┐
│ ● ARMÉ    Wi-Fi ▊▊▊▁▁  RTT 78 ms       🔋 61 %   Mission : 2/5 waypoints   │
├──────────────────────────────────────────────────┬─────────────────────────┤
│                                                  │  WAYPOINTS              │
│      ╭──── carte Leaflet, tuiles hors ligne ───╮ │  ▸ 1 ✔ atteint          │
│      │                                          │ │  ▸ 2 ✔ atteint          │
│      │        ②────────③                        │ │  ▸ 3 ◉ en cours  12 m   │
│      │       ╱          ╲                       │ │  ▸ 4   en attente       │
│      │      ①            ④                      │ │  ▸ 5   en attente       │
│      │      │      🤖    │                      │ │                         │
│      │      │      ▲     │                      │ │  [Y] poser un point     │
│      │      ╰──── ⑤ ─────╯                      │ │  [A] démarrer           │
│      ╰──────────────────────────────────────────╯ │  [B] ARRÊT              │
│         ⊕ position GPS ±2,8 m · 9 satellites      │  [croix] sélectionner   │
├──────────────────────────────────────────────────┴─────────────────────────┤
│  ╔══════════════════════════════════════════════════════════════════════╗  │
│  ║   ZL RELÂCHÉ — conduite inhibée · mission autonome autorisée         ║  │
│  ╚══════════════════════════════════════════════════════════════════════╝  │
└────────────────────────────────────────────────────────────────────────────┘
```

Carte : **Leaflet 1.9.4** + tuiles raster hors connexion. Deux façons de les servir depuis le robot, et je recommande la première :

| Solution | Détail |
|---|---|
| ✅ **PMTiles + nginx** | Une archive `.pmtiles` unique posée sur nginx, lue côté navigateur par `pmtiles@4.4.1` en requêtes HTTP Range. **Aucun serveur de tuiles**, nginx gère les Range nativement. |
| 🟡 Tuiles PNG statiques | Arborescence `/{z}/{x}/{y}.png` servie en statique. Zéro dépendance JS, mais des dizaines de milliers de fichiers. |
| ❌ MBTiles + tileserver-gl | `tileserver-gl` **n'est pas dans les dépôts Ubuntu noble** ✅ — il faudrait ajouter Node.js et un service à surveiller sur le robot. |

📐 Compter 50–200 Mo pour une zone de 10 × 10 km jusqu'au niveau z18. Extraction avec `gdal2tiles.py` (`gdal-bin`, présent dans noble ✅).

⚠️ **Pas MapLibre GL ni OpenLayers** : ils exigent WebGL, ce qui pèse lourd sur un Tegra X1. Et le besoin réel — quelques dizaines de marqueurs et une polyligne — ne justifie pas un rendu vectoriel. Leaflet en Canvas suffit très largement.

### Mode DIAG

Rapport d'auto-test [P1]–[P7] du §K, tensions des 10 cellules avec leur delta, températures, compteurs d'erreurs CAN, journal des 20 derniers événements. **Et une section « pupitre »** : identifiant et mapping de la manette détectée, valeur brute des 4 axes au repos (détection de dérive), RTT, débit, version de l'IHM.

⚠️ **Cette section « pupitre » n'est pas du confort.** C'est ce qui permet de diagnostiquer en trente secondes le cas *« j'appuie et il ne se passe rien »* — manette non fusionnée (joycond), mapping vide (mauvais navigateur), contexte non sécurisé (HTTP au lieu de HTTPS), stick qui dérive.

### Rendu du lidar et de la carte d'occupation

Fait maison, en **Canvas 2D empilés** (fond statique / scan dynamique / surcouches). Ce n'est pas un pis-aller :

- `nav_msgs/OccupancyGrid` → un `Uint8ClampedArray` RGBA construit depuis `data[]` (−1 inconnu → gris, 0 libre → blanc, 100 occupé → noir), `putImageData` sur un canvas hors-écran, affiché par transformation affine depuis `info.origin` et `info.resolution`. **~40 lignes**, et on ne redessine qu'à réception.
- `sensor_msgs/LaserScan` → 714 points par scan à 7 Hz, soit ~5 000 opérations/s. Aucun problème même sur un Cortex-A57.

`ros2djs` et `ros3djs` sont morts (dernière publication 2022-05-03, `ros3djs` épingle `three@0.89` contre 0.185 aujourd'hui) ✅ — les ressusciter coûterait plus cher que d'écrire les 40 lignes.

---

## W.7 Démarrage du pupitre

### Configuration de la Switch

```bash
# 1. Firefox depuis le dépôt Mozilla (le Chromium switchroot est figé en 126)
sudo add-apt-repository ppa:mozillateam/ppa
sudo apt install firefox

# 2. ⚠️ Neutraliser le mapping stick → curseur souris
sudo mv /usr/share/X11/xorg.conf.d/50-joystick.conf{,.disabled}

# 3. joycond doit tourner
systemctl status joycond

# 4. Certificat du robot dans le magasin de confiance de Firefox
#    (Paramètres → Vie privée → Certificats → Autorités → Importer)

# 5. Économie d'énergie
#    - profil nvpmodel « Handheld » dans la barre des tâches
#    - option de boot dvfsb=1 (Switch 2019 / Lite / OLED uniquement)
xset s off && xset s noblank && xset -dpms
```

### Procédure de mise en route, dans l'ordre

```
1. Allumer la Switch, ouvrir Firefox sur https://retriever.local/
2. ⚠️ APPUYER SUR L + R  → joycond fusionne les deux Joy-Con
   (obligatoire à CHAQUE démarrage : la fusion n'est déclenchée
    que par un événement evdev)
3. ⚠️ Appuyer sur n'importe quel bouton avec la page VISIBLE
   → Firefox n'expose la manette qu'après une interaction
4. L'IHM affiche « Manette : Nintendo Switch Combined Joy-Cons
   — mapping standard ✔ »   … sinon, voir W.6 mode DIAG
5. Test de repos des sticks (automatique, 1 s)
6. [A] appui long → demande d'armement
7. Le robot répond : accordé, ou refusé avec la liste des
   conditions non satisfaites (§J.2)
```

⚠️ Les étapes 2 et 3 sont contre-intuitives et **doivent figurer sur une étiquette collée au dos de la Switch**. Sans elles, l'interface semble simplement cassée.

### Mode kiosque (optionnel, phase ultérieure)

`~/.xinitrc` avec `matchbox-window-manager`, `unclutter-xfixes` et Firefox en `--kiosk`. Paquets présents dans noble ✅. À ne faire qu'une fois l'IHM stabilisée : en développement, un bureau normal est plus pratique.

### Énergie

🔴 **Aucune mesure d'autonomie sous switchroot n'est publiée.** Je ne l'invente pas. Ce qui est documenté :

- Batterie **16,0 Wh** (13,2 Wh sur Lite) ✅
- **Deep Sleep** supporté ✅
- Profils `nvpmodel` commutables ; le profil « Handheld » bride CPU/GPU ✅
- Option de boot **`dvfsb=1`** sur Mariko : *« reduces power draw for the same performance »* ✅ — levier gratuit
- Charge en USB-C PD pendant l'usage ✅

📐 **Recommandation pragmatique** : mesurer l'autonomie réelle dès la première session (`/sys/class/power_supply/`), et prévoir dans tous les cas **une batterie externe USB-C PD**. Un pupitre qui s'éteint en pleine manœuvre est un mode de défaillance que l'architecture gère (perte de heartbeat → arrêt en rampe), mais qu'il vaut mieux ne pas provoquer.

---

## W.8 Modes de défaillance propres au pupitre

| # | Panne | Détection | Réaction | Niveau |
|---:|---|---|---|---|
| 35 | Wi-Fi perdu en téléopération | Heartbeat > 500 ms | Verrou `twist_mux`, arrêt en rampe 0,8 s, **réarmement explicite requis** | **DEGRADED** |
| 36 | **Onglet passé en arrière-plan / écran verrouillé** | `visibilitychange`, `blur` | ⚠️ Homme-mort relâché **côté client**, immédiatement. Le throttling des timers en arrière-plan rendrait la cadence de 20 Hz caduque | — |
| 37 | Manette débranchée / joycond redémarré | `gamepaddisconnected` | Homme-mort relâché, bandeau rouge | — |
| 38 | **Stick qui dérive** | Test de repos à l'armement (< 5 % pendant 1 s) | Armement refusé, valeur affichée | **refus** |
| 39 | Dérive apparue **en cours de session** | Valeur non nulle > 30 s alors que l'homme-mort est relâché | Avertissement persistant, plafond de vitesse réduit à 0,3 m/s | **WARN** |
| 40 | Batterie du pupitre vide | Extinction brutale | = panne 35 | **DEGRADED** |
| 41 | Firefox plante | Perte du WebSocket | = panne 35 | **DEGRADED** |
| 42 | RTT dégradé (> 300 ms) | Mesuré par le heartbeat | IHM grisée, dégradation adaptative (vidéo puis lidar), plafond de vitesse abaissé | **WARN** |
| 43 | Manette non fusionnée au boot | `navigator.getGamepads()` vide | Bandeau *« Appuyez sur L + R »* | **info** |
| 44 | **Mauvais navigateur / HTTP au lieu de HTTPS** | Manette vide alors que le système la voit | Bandeau explicite *« Contexte non sécurisé : Firefox n'expose pas les manettes en HTTP »* | **info** |
| 45 | Deux pupitres connectés en même temps | Deux clients rosbridge publient | ⚠️ **Le superviseur n'accepte qu'une session de conduite** : le premier armé garde la main, le second est en lecture seule avec un bandeau explicite | **info** |

⚠️ **La panne 45 est facile à oublier et dangereuse** : un collègue qui ouvre l'IHM « juste pour voir » depuis un PC ne doit pas pouvoir prendre le contrôle en parallèle. Un jeton de session de conduite, attribué à l'armement et libéré au désarmement, résout le problème en quelques lignes.

⚠️ **La panne 36 est la plus sournoise.** Le navigateur ralentit volontairement les timers d'un onglet en arrière-plan. Si l'opérateur bascule vers une autre fenêtre en tenant ZL, la boucle à 20 Hz passe à 1 Hz et la commande devient erratique. Traiter `visibilitychange` comme un relâchement d'homme-mort est **obligatoire**, pas optionnel.

---

## W.9 Plan de réalisation

S'insère après la **Phase 5** du §V (premiers déplacements) — et une partie peut se faire bien plus tôt, contre le matériel simulé.

| Phase | Contenu | Critère de sortie | Peut démarrer |
|---|---|---|---|
| **W-A · Valider la Switch** ⚠️ | Les 5 tests ci-dessous | Manette combinée visible dans Firefox avec `mapping: "standard"` | **Tout de suite** |
| **W-B · Socle IHM** | nginx + TLS, rosbridge, PWA conduite + télémétrie, `retriever_teleop_guard`, homme-mort, heartbeat | Conduite d'un robot **simulé** (`use_mock_hardware:=true`) depuis la Switch | Après Phase 1 |
| **W-C · Sécurité de la téléop** | Tests d'injection de panne : coupure Wi-Fi, onglet masqué, manette débranchée, RTT dégradé | Arrêt en rampe < 1,8 s dans tous les cas, réarmement explicite vérifié | Après W-B |
| **W-D · Capteurs** | Vue lidar Canvas, `web_video_server`, dégradation adaptative | Lidar à 7 Hz et vidéo à 10 fps sous 2 Mbit/s mesurés | Après Phase 6 |
| **W-E · Missions** | Leaflet + PMTiles hors ligne, actions Nav2, édition de waypoints | Mission GPS 3 points lancée et suivie depuis la Switch | Après Phase 7 |
| **W-F · Durcissement** | Mode kiosque, jeton de session, mesure d'autonomie, étiquettes de procédure | Session de terrain de 30 min sans intervention | Après W-E |

### ⚠️ Les cinq tests de la phase W-A — à faire avant toute ligne de code

Ils prennent une demi-heure et peuvent invalider tout le reste du chapitre.

| # | Commande | Ce qu'on cherche |
|---:|---|---|
| 1 | `cat /proc/bus/input/devices` | Confirmer `Nintendo Switch Left/Right Joy-Con Serial`, PID `2006` / `2007`, et la présence ou non d'un périphérique IMU |
| 2 | `systemctl status joycond`, puis **appuyer L+R** | Voir apparaître `Nintendo Switch Combined Joy-Cons` (`057e:2008`) et son `/dev/input/js*` |
| 3 | Ouvrir un testeur de manette **en HTTPS ou sur `localhost`**, dans **Firefox** puis dans **Chromium** | Comparer `gamepad.id`, `gamepad.mapping`, le nombre d'axes et de boutons. ⚠️ **C'est ce test qui tranche l'hypothèse « Chromium ne voit rien »** |
| 4 | `evtest` sur le périphérique combiné, sticks relâchés, 60 s | Mesurer la dérive réelle → dimensionner la zone morte applicative |
| 5 | `cat /sys/class/power_supply/*/current_now` pendant 30 min d'IHM | Obtenir enfin un chiffre d'autonomie |

**Si le test 3 échoue dans les deux navigateurs**, il reste deux issues avant d'abandonner la Switch : un petit démon local qui lit evdev et relaie en WebSocket vers la page (contourne entièrement l'API Gamepad), ou une manette USB/Bluetooth externe branchée sur la Switch. Aucune des deux n'est bloquante pour l'architecture — le pupitre reste un client léger interchangeable.

---

## W.10 Ce que ça ajoute au BOM

| Élément | Qté | Fonction | Prix 📐 | Priorité |
|---|---:|---|---:|---|
| **E-stop radio (émetteur + récepteur, contact NF)** | 1 | ⚠️ **Passe de recommandé à impératif** dès que la téléop est en service | 90 € | ★★★ **impératif** |
| Caméra USB RGB grand angle (UVC, 640×480 suffit) | 1 | Retour visuel de conduite — le Kinect est inutilisable en extérieur (§N.4) | 35 € | ★★★ |
| Point d'accès Wi-Fi / carte M.2 en mode AP | 1 | Réseau de terrain isolé | 0–40 € | ★★ |
| Batterie externe USB-C PD 30 W | 1 | Autonomie du pupitre | 35 € | ★★ |
| Sangle / harnais de cou pour la Switch | 1 | Deux mains sur la manette, pas sur la console | 15 € | ★★ |
| Carte microSD 128 Go U3/A2 | 1 | Requise par switchroot (16 Go minimum) | 20 € | ★ |
| Film antireflet | 1 | Écran brillant + soleil = illisible | 10 € | ★ |

📐 **Sous-total : ≈ 245 €**, dont 90 € qui relèvent de la sécurité.

---

## W.11 En résumé

**Ce qui est solide** : l'architecture client léger est la bonne, elle découle directement du §O ; toutes les briques ROS 2 existent et sont maintenues (rosbridge 2.7.0 très actif, roslib 2.1.0 réécrit en 2026) ; le budget réseau tient largement (1,9 Mbit/s sur un lien qui en offre 15–30) ; la sécurité de la téléop est traitable avec des mécanismes éprouvés.

**Ce qui est fragile** : la Switch elle-même. Noyau 4.9, Chromium abandonné à la 126, chaîne d'entrée à quatre étages (serdev → joycond → uinput → evdev) à valider empiriquement, sticks qui dérivent, autonomie inconnue. **Aucun de ces points n'est bloquant pour le robot** — parce que le pupitre est interchangeable et que sa perte est un cas nominal géré par le superviseur. Mais il faut faire la phase W-A avant d'investir du temps dans l'IHM.

**Ce qui manque et qu'il faut acheter** : l'e-stop radio. Piloter à 30 m un robot de 35 kg dont le seul arrêt d'urgence est un champignon fixé sur le robot lui-même, c'est le trou de l'architecture actuelle.

**Le point à ne pas oublier** : le bouton rouge de l'écran n'est **pas** un arrêt d'urgence, et ne doit jamais être étiqueté comme tel.

---

### Sources de cette section

[Switchroot Wiki — Linux Features](https://wiki.switchroot.org/wiki/linux/linux-features.md) · [Guide Ubuntu Noble](https://wiki.switchroot.org/wiki/linux/l4t-ubuntu-noble-installation-guide.md) · [Changelog Linux switchroot](https://wiki.switchroot.org/wiki/linux/linux-changelog) · [CTCaer/switch-l4t-kernel-4.9](https://github.com/CTCaer/switch-l4t-kernel-4.9) · [CTCaer/joycond](https://github.com/CTCaer/joycond) · [DanielOgorchock/joycond](https://github.com/DanielOgorchock/joycond) · [chromium/device/gamepad](https://github.com/chromium/chromium/tree/main/device/gamepad) · [gecko-dev/dom/gamepad](https://github.com/mozilla/gecko-dev/tree/master/dom/gamepad) · [Mozilla Hacks — Securing the Gamepad API](https://hacks.mozilla.org/2020/07/securing-gamepad-api/) · [MDN — Using the Gamepad API](https://developer.mozilla.org/en-US/docs/Web/API/Gamepad_API/Using_the_Gamepad_API) · [RobotWebTools/rosbridge_suite — protocole v2](https://github.com/RobotWebTools/rosbridge_suite/blob/ros2/ROSBRIDGE_PROTOCOL.md) · [roslibjs](https://github.com/RobotWebTools/roslibjs) · [RobotWebTools/web_video_server](https://github.com/RobotWebTools/web_video_server/blob/ros2/README.md) · [foxglove/foxglove-sdk](https://github.com/foxglove/foxglove-sdk) · [Foxglove vs Foxglove Studio, two years on](https://foxglove.dev/blog/foxglove-vs-foxglove-studio-two-years-on) · [lichtblick-suite/lichtblick](https://github.com/lichtblick-suite/lichtblick) · [Leaflet](https://leafletjs.com/) · [protomaps/PMTiles](https://github.com/protomaps/PMTiles) · [IEC 62745:2017](https://webstore.iec.ch/en/publication/31998) · [Machinery Safety 101 — Wireless E-stop](https://machinerysafety101.com/2026/05/25/wireless-estop/) · [ISO 3691-4:2023 (preview ANSI)](https://webstore.ansi.org/preview-pages/ISO/preview_ISO+3691-4-2023.pdf) · [Fictionlab — WebRTC on robots](https://fictionlab.pl/blog/webrtc-on-robots-how-to-stream-live-video-from-your-rover-to-any-browser/) · [iFixit — batterie HAC-003](https://www.ifixit.com/products/nintendo-switch-console-replacement-battery)

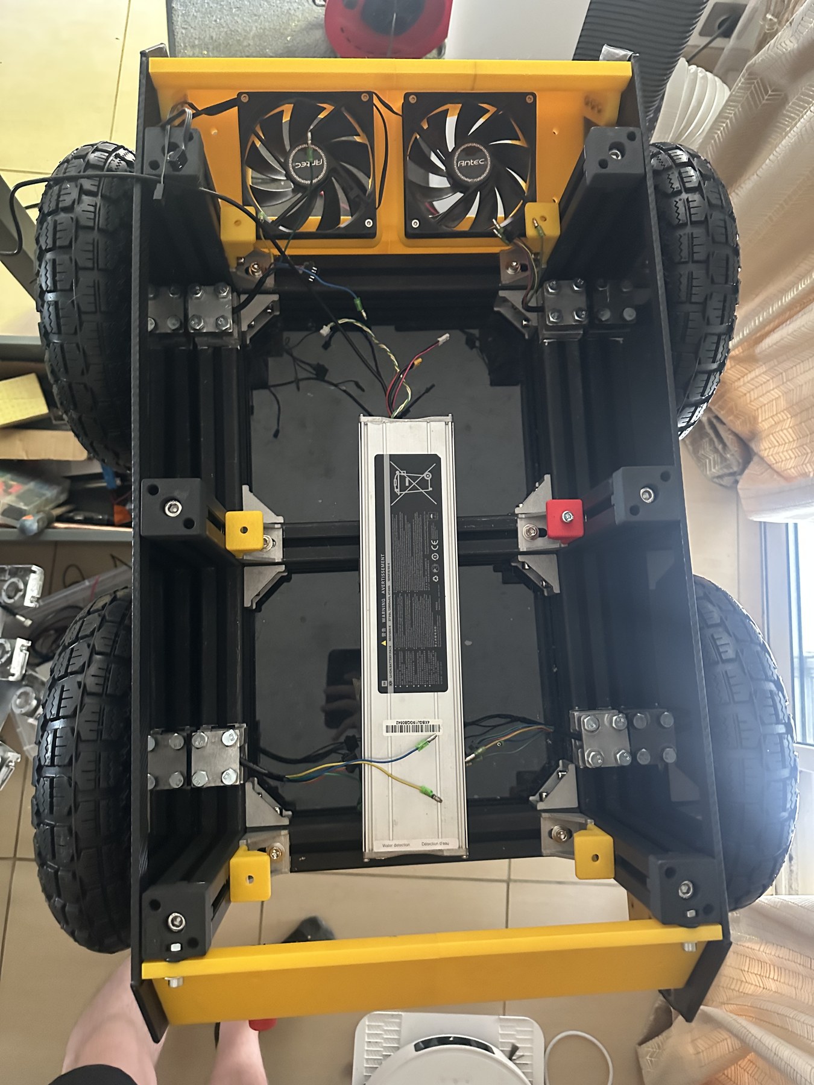
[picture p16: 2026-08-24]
docs/images/build/b05-img_8104.jpg

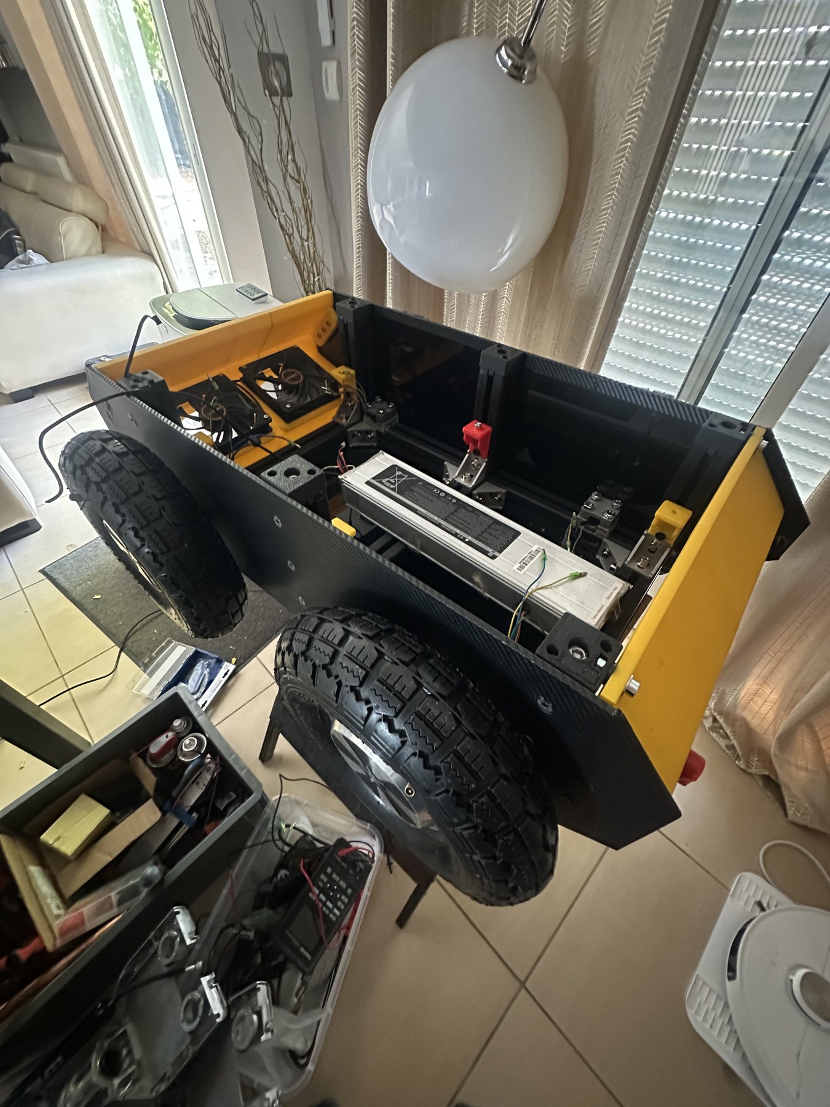
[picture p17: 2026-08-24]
docs/images/build/b02-img_8102.jpg

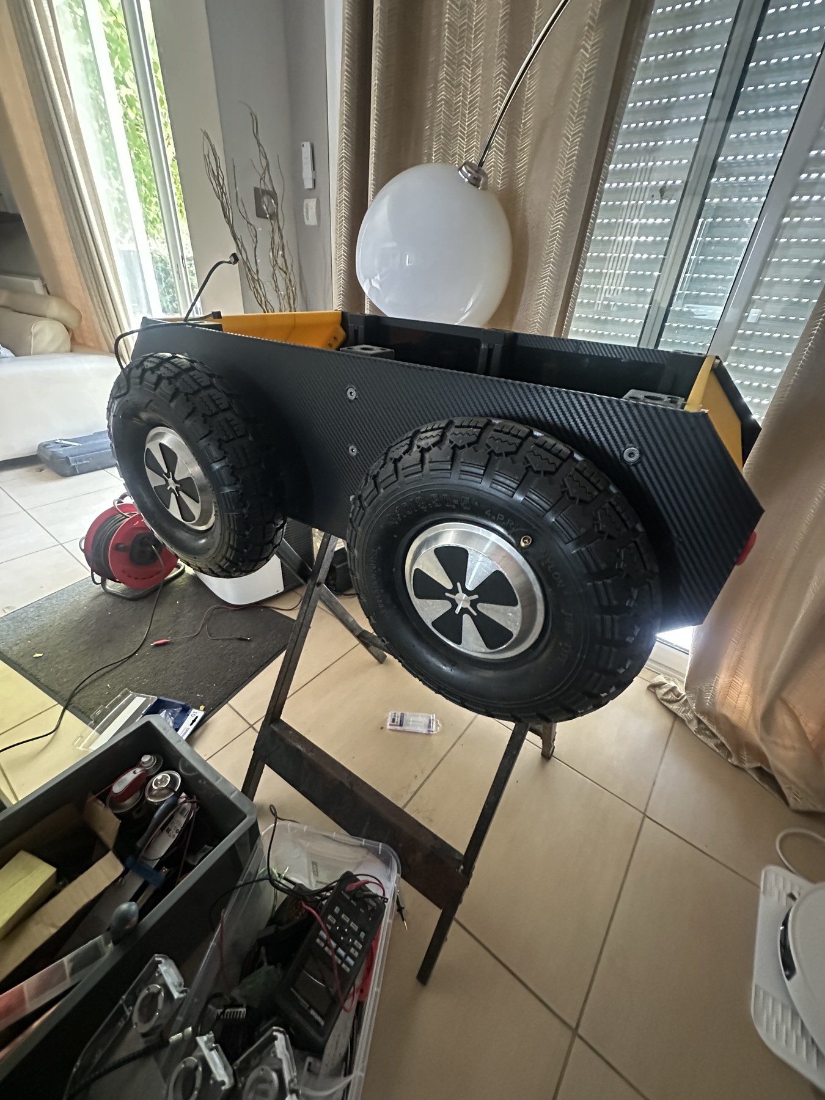
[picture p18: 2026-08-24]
docs/images/build/b06-img_8103.jpg

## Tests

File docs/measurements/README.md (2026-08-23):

# Bench measurements

Results go here, one file per measurement, named `M<n>-<short-name>.md`.

Each of these blocks a design decision. Nothing that depends on a measurement
gets wired before the measurement exists.

| # | Measurement | Blocks | Status |
|---|---|---|---|
| M1 | Battery BMS current cut off threshold | Current budget, main fuse rating, number of driven wheels | to do |
| M2 | Pack voltage at rest and under load, internal resistance | Prospective short circuit current, fuse breaking capacity | to do |
| M3 | BMS connector logic level and pinout | Safety controller to BMS wiring | to do |
| M4 | Motor driver EL and STOP input polarity | The whole stop chain, levels 3 to 5 | to do |
| M5 | Motor driver J1 jumper state | PWM versus analogue command | to do |
| M6 | Motor pole pair count | Odometry constant | to do |
| M7 | Hall output voltage and impedance | Signal conditioning circuit | to do |
| M8 | No load and loaded current per motor | Current budget, cable sizing | to do |
| M9 | SBC USB 3.0 controller model | Whether the depth camera works at all | to do |
| M10 | Total bus input capacitance | Precharge resistor and duration | to do |
| M11 | GNSS supply voltage and protocol | Power rail, ROS 2 driver | to do |
| M12 | Motor driver input capacitor voltage rating | Whether a fully charged pack is safe | to do |

Template for a result file:

```markdown
# M<n> : <name>

**Date:**
**Method:**
**Instruments:**
**Protection in place:**

## Raw data

## Result

## Decision unblocked
```

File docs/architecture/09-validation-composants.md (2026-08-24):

# Y. Validation des composants par datasheet

**Version** : 1.0 — 24 août 2026
**Objet** : vérification, source primaire à l'appui, de chaque composant retenu pour `safety_power`, `motor_interface` et `safety_bus_distribution`. Aucune valeur de ce document ne provient de mémoire : chaque ligne a été relue dans une datasheet constructeur récupérée, dont l'URL est citée.

**Statut de chaque fait** :

| Marqueur | Signification |
|---|---|
| ✅ **VÉRIFIÉ** | Lu dans une datasheet constructeur |
| 🟡 **CONSENSUS** | Plusieurs sources indépendantes non officielles concordantes |
| 🔴 **CONTRADICTOIRE / INCONNU** | Sources divergentes, ou aucune source |
| ⚠️ **CONSÉQUENCE** | Impact direct sur la conception |
| 📐 **DÉRIVÉ** | Calcul ou raisonnement de ma part à partir des faits ci-dessus |

---

# Y.0 Les cinq découvertes qui changent la conception

Avant le détail, les cinq points qui invalident ou corrigent ce qui était écrit dans les README ou le dossier v1.1.

| # | Découverte | Ce qui était écrit | Ce qu'il faut faire |
|---|---|---|---|
| **Y.0.1** | ⚠️ **Le `SN74LVC14A` ne garantit plus `Ioff`.** TI a **retiré** de la datasheet la mention « Ioff Supports Live Insertion, Partial-Power-Down Mode and Back Drive Protection », et écrit désormais : *« The inputs to this device have negative clamping diodes. The outputs to this device have both positive and negative clamping diodes. »* ✅ | Le README `motor_interface` fonde son **exigence dure** sur ce composant : « le passthrough survit à la perte du 3,3 V » | **Changer de référence.** Le `SN74LVC3G17` garantit explicitement *« Ioff Supports Live Insertion, Partial-Power-Down Mode and Back Drive Protection »* ✅. C'est le seul choix compatible avec l'exigence. |
| **Y.0.2** | ⚠️ **L'entraxe des rangées d'une DevKitC V4 38 broches est 25,40 mm (1,0"), pas 22,86 mm.** Le plan coté officiel Espressif donne carte 48,26 × 27,94 mm, rangées à 1,27 mm de chaque bord ✅ | Le README `motor_interface` annonce « 22.86 mm row pitch » | **Corriger le footprint.** 22,86 mm (0,9") est l'entraxe des cartes **tierces 30 broches**, qu'Espressif ne documente pas. Un PCB percé à 22,86 n'acceptera jamais la carte. |
| **Y.0.3** | ⚠️ **Sur le ZS-X11H, `BRAKE`/`EL` est actif-HAUT et `STOP` est actif-BAS = roue libre.** Mesure au banc publiée + 2 listings vendeurs concordants 🟡 | Le dossier §H.7 suppose que tirer `/SAFE` à la masse **freine** les moteurs | **Toute la chaîne d'arrêt d'urgence est à revoir.** Voir Y.4.3 — c'est la découverte la plus importante du document. |
| **Y.0.4** | ⚠️ **Le `2N7002` n'est pas garanti passant sous 3,3 V de grille.** `VGS(th)` jusqu'à **2,5 V max** à 25 °C et **2,75 V à −55 °C**, et **aucun `RDS(on)` spécifié en dessous de VGS = 4,5 V** ✅ | Le dossier §F.5-L3 et §H.3 retiennent le 2N7002 pour tous les étages collecteur ouvert | Remplacer par **`DMG1012T`** (`RDS(on)` ≤ 0,5 Ω garanti à VGS = 2,5 V ✅) ou **`BSS138` onsemi** (`VGS(th)` ≤ 1,5 V ✅). |
| **Y.0.5** | ⚠️ **Aucun eFuse `TPS2595` ne tient le bus 42 V** : plage 2,7–18 V, abs max 20 V ✅ | X.5.4 de la revue proposait le TPS2595 | Sur le bus : **`TPS2663x`** ou **`TPS2662x`** (4,5–60 V, abs max 67 V / 62 V ✅). Le TPS2595 reste valable sur les rails **12 V et 5 V** uniquement. |

---

# Y.1 Bus CAN

## Y.1.1 Transceiver — `TCAN1042HV` retenu

[Datasheet TI TCAN1042HV](https://www.ti.com/lit/ds/symlink/tcan1042hv.pdf)

**Signification des suffixes** ✅ — à lire attentivement, c'est la source d'erreur de commande la plus fréquente :

| Suffixe | Effet |
|---|---|
| `H` | Tenue de défaut bus **±70 V** au lieu de ±58 V |
| `V` | **Broche `VIO` présente** — c'est ce suffixe, et lui seul, qui donne l'adaptation de niveau |
| `G` | CAN FD 5 Mbit/s au lieu de 2 |
| `D` / `DR` / `DRB` | SOIC-8 / SOIC-8 bobine / VSON-8 3 × 3 mm |

→ **Référence retenue : `TCAN1042HVDR`** — ±70 V, `VIO`, SOIC-8, bobine.

| Paramètre | Valeur ✅ |
|---|---|
| `VCC` | **4,5 – 5,5 V** — ⚠️ c'est un transceiver **5 V**, pas 3,3 V |
| `VIO` | 3,0 – 5,5 V |
| Tenue de défaut `CANH`/`CANL` | **±70 V** (±58 V sans le `H`) |
| Mode commun récepteur | **±30 V** en mode normal ; ±12 V en standby ; ⚠️ **−2 à +7 V seulement si 3,0 V ≤ VIO ≤ 4,5 V** |
| Brochage SOIC-8 | 1 `TXD` · 2 `GND` · 3 `VCC` · 4 `RXD` · 5 `VIO` · 6 `CANL` · 7 `CANH` · 8 `STB` |
| Débit | 2 Mbit/s (5 sur suffixe `G`) — largement au-dessus des 500 kbit/s retenus |
| Courant standby | 0,5 µA typ / 5 µA max |
| ESD | ±16 kV HBM, ±15 kV IEC |

**Composants externes exigés par le schéma d'application** ✅ :

- `VCC` : **4,7 µF** bulk + **0,1 µF** au plus près de la broche
- `VIO` : **0,1 µF** au plus près
- ⚠️ **`STB` a un pull-up interne : la broche laissée flottante met le composant en STANDBY.** Elle **doit** être tirée explicitement à `GND` pour le mode normal. Une erreur classique qui donne un bus muet sans message d'erreur. La valeur du pull-up n'est pas publiée.
- Terminaison fendue : 2 × 60 Ω avec `CSPLIT` au point milieu vers `GND`

🔴 **Deux points non vérifiables** :
1. La valeur de `CSPLIT` n'apparaît pas dans le **texte** de la datasheet, seulement dans la figure 10-2. La convention du secteur est 4,7 nF — ce n'est pas une spécification TI. → **À lire visuellement sur la figure avant de figer.**
2. La révision courante du PDF semble avoir retiré les variantes non-`H`. → **Vérifier les références commandables actives sur ti.com avant BOM.**

## Y.1.2 Pourquoi abandonner le `SN65HVD230`

[Datasheet TI SN65HVD230](https://www.ti.com/lit/ds/symlink/sn65hvd230.pdf)

| Paramètre | SN65HVD230 ✅ | TCAN1042HV ✅ |
|---|---|---|
| **Tenue de défaut bus (abs max)** | **−4 V à +16 V** | **±70 V** |
| Mode commun | −2 à +7 V | ±30 V |
| `VCC` | 3,0 – 3,6 V (3,3 V natif) | 4,5 – 5,5 V + `VIO` |
| CAN FD | non | oui |

⚠️ **C'est un facteur ~4,4 sur la tenue de défaut.** Sur un robot où le CAN, le 12 V et le 42 V cheminent dans le même faisceau, un contact accidentel entre une ligne de puissance et `CANH` détruit **simultanément les quatre nœuds** avec un HVD230. Avec le TCAN1042HV, ±70 V couvre largement les 42 V du bus.

Le HVD230 garde un avantage : son alimentation 3,3 V unique. Le TCAN1042HV impose un rail 5 V sur chaque carte — ce qui est de toute façon nécessaire ailleurs (Hall, DAC, ampli VR).

**Note utile pour la broche `Rs` du HVD230**, si tu en gardes en stock : `Rs` < 1,2 V = haute vitesse ; 10 k–100 k vers `GND` = contrôle de pente ; `Rs` > 0,75 × `VCC` = standby ✅.

## Y.1.3 `TCAN1051` — la différence à connaître

[Datasheet TI TCAN1051HV](https://www.ti.com/lit/ds/symlink/tcan1051hv.pdf)

Brochage identique sur 1–7. **La seule différence est la broche 8** : `S` (Silent mode) au lieu de `STB` (Standby). En silent mode le **récepteur reste actif** — on continue d'écouter le bus sans pouvoir émettre. Coût : **1,5 à 2,5 mA** au lieu de quelques µA ✅.

📐 **Pour ce robot, le `TCAN1042` suffit** : aucun nœud n'a besoin d'un mode « écoute seule », et le standby très basse consommation est plus utile sur le nœud SAFETY alimenté en amont du contacteur.

## Y.1.4 Protection ESD du bus

| Composant | `VRWM` | `VBR` | Clamp | Capacité | Boîtier |
|---|---|---|---|---|---|
| [**Nexperia PESD1CAN**](https://assets.nexperia.com/documents/data-sheet/PESD1CAN.pdf) | 24 V | 25,4–30,3 V @ 5 mA | 40 V @ 1 A · 70 V @ 3 A | **11–17 pF** | SOT-23 |
| [**onsemi NUP2105L**](https://www.onsemi.com/download/data-sheet/pdf/nup2105l-d.pdf) | 24 V | 26,2–32 V @ 1 mA | **33–40 V @ 5 A** · 37–44 V @ 8 A | 26 pF | SOT-23 |

📐 **Choix : `NUP2105L`.** À 500 kbit/s la capacité n'a aucune importance (le PESD1CAN ne prend l'avantage qu'en CAN FD rapide), et le NUP2105L **clampe nettement plus bas à fort courant** — 40 V à 5 A contre 70 V à 3 A. C'est la robustesse en surtension qui compte ici, pas la bande passante.

## Y.1.5 Self de mode commun

[Datasheet TDK ACT45B](https://www.tdk-electronics.tdk.com/inf/30/ds/act45b.pdf) — série explicitement destinée au CAN bus.

| Référence | L | Impédance @ 10 MHz | Courant nominal | DCR max | Boîtier |
|---|---|---|---|---|---|
| `ACT45B-510-2P-TL003` | 51 µH | 2 800 Ω typ | **200 mA** | **1,0 Ω** | EIA 1812 |
| `ACT45B-101-2P-TL003` | 100 µH | 5 800 Ω typ | 150 mA | 2,0 Ω | EIA 1812 |

→ **`ACT45B-510`** : 200 mA et 1 Ω de DCR, largement au-dessus du courant de signal CAN, et 2,8 kΩ à 10 MHz suffisent contre le hachage des variateurs. Disponible chez JLCPCB (C88056) ✅.

⚠️ Le Würth `744232222` est un composant data-line générique dont la datasheet ne tabule **aucune impédance de mode commun** (courbe seulement) 🔴. La série TDK est la seule des deux dont la documentation cite explicitement le CAN.

---

# Y.2 Tampon des signaux Hall — le point critique

## Y.2.1 ⚠️ `SN74LVC14A` : `Ioff` n'est plus garanti

[Datasheet TI SN74LVC14A](https://www.ti.com/lit/ds/symlink/sn74lvc14a.pdf)

| Paramètre | Valeur ✅ |
|---|---|
| `VCC` | **1,65 – 3,6 V** — ⚠️ pas 5,5 V |
| Tolérance d'entrée | `VI` abs max 6,5 V ; « Inputs accept voltages to 5,5 V » → **5,5 V tolérant à VCC = 3,3 V** |
| `VT+` / `VT−` à VCC = 3,0 V | 0,9–2,0 V / 0,6–1,5 V (hystérésis 0,3–1,2 V) |
| `IIK` abs max | −50 mA |
| `IOK` abs max | ±50 mA |
| Courant continu total par `VCC` ou `GND` | **±100 mA** |
| **`Ioff` / partial-power-down** | ❌ **NON.** Les mots `Ioff`, *partial-power-down* et *live insertion* **n'apparaissent plus** dans la révision courante, et l'historique de révision note explicitement leur **suppression**. §8.3.3 : *« The inputs to this device have negative clamping diodes. The outputs to this device have both positive and negative clamping diodes. »* |

⚠️ **Conséquence directe** : le README `motor_interface` écrit son exigence dure comme suit —

> « Si l'ESP32 est retiré, non alimenté ou défaillant, le lien moteur → contrôleur doit continuer de fonctionner. »

Cette garantie repose entièrement sur le comportement du tampon quand `VCC` = 0. **TI ne la garantit plus sur le LVC14A.** Ce n'est pas une subtilité de datasheet : c'est le fondement de la carte.

## Y.2.2 `SN74LVC3G17` — le remplaçant

[Datasheet TI SN74LVC3G17](https://www.ti.com/lit/ds/symlink/sn74lvc3g17.pdf)

| Paramètre | Valeur ✅ |
|---|---|
| Fonction | **Triple buffer Schmitt NON inverseur** (Y = A) |
| `VCC` | **1,65 – 5,5 V** |
| Tolérance d'entrée | `VI` abs max 6,5 V, 5,5 V tolérant à VCC = 3,3 V |
| `VT+` à 3,3 V | **1,50 – 1,87 V** |
| `VT−` à 3,3 V | **0,84 – 1,14 V** |
| **Hystérésis garantie** | **0,56 – 0,87 V** |
| Sortie | ±24 mA à 3,3 V |
| **`Ioff`** | ✅ **OUI, explicitement** : *« Ioff Supports Live Insertion, Partial-Power-Down Mode and Back Drive Protection »* |
| `IIK` abs max | −50 mA |
| Boîtiers | DCT (SSOP-8), DCU (VSSOP-8), YZP (DSBGA-8) |
| Brochage 8 br. | 1 `1A` · 2 `3Y` · 3 `2A` · 4 `GND` · 5 `2Y` · 6 `3A` · 7 `1Y` · 8 `VCC` |

**Trois avantages simultanés sur le LVC14A** :
1. `Ioff` garanti — l'exigence dure est tenue.
2. **Non inverseur** — la table d'états Hall n'a plus à être complémentée en firmware.
3. `VCC` jusqu'à 5,5 V — le tampon peut être alimenté en 5 V si on décide un jour de le référencer au rail moteur.

📐 **Pour 6 canaux (carte 2 moteurs, 3 Hall par moteur) : 2 × `SN74LVC3G17`.** Zéro canal gaspillé, exactement le compte.

**Repli** si rupture : `SN74LVC2G17` (dual) ou `SN74LVC1G17` (single), tous deux avec `Ioff` ✅. Noter que les seuils du 2G17 sont plus lâches (`VT+` jusqu'à 2,0 V) que ceux du 1G17 et du 3G17 — si l'hystérésis minimale compte, préférer **1G17 ou 3G17**.

⚠️ **Interdit de substitution, à écrire dans la BOM** :
- ❌ `74HC14` / `74HCT14` — clamp vers `VCC`, cassent l'exigence hors tension
- ❌ `SN74LVC14A` — `Ioff` non garanti (Y.2.1)
- 🟡 `74LV17A` Nexperia (hex, non inverseur) est un repli acceptable — `IOFF` documenté ✅, `VCC` 2,0–5,5 V, entrées tolérantes 7 V — **mais** `IIK` abs max n'est que **−20 mA** (contre −50 mA en LVC), ce qui réduit la marge de protection contre un contact de phase, et ses seuils à 3,3 V ne sont donnés qu'en **typiques**, pas en min/max garantis 🔴. [Datasheet 74LV17A](https://www.mouser.com/datasheet/2/916/74LV17A-1318318.pdf)

## Y.2.3 Clamp de protection : `BAT54S`

[Datasheet Nexperia BAT54S](https://assets.nexperia.com/documents/data-sheet/BAT54S.pdf)

**Configurations de la série** ✅ — c'est là que tout le monde se trompe :

| Variante | Config | Pin 1 | Pin 2 | Pin 3 |
|---|---|---|---|---|
| `BAT54A` | anode commune | K1 | K2 | **A1+A2** |
| `BAT54C` | cathode commune | A1 | A2 | **K1+K2** |
| **`BAT54S`** | **série** | A1 | K2 | **K1 + A2** |

📐 **Pour clamper un signal entre `GND` et `+3,3 V`, il faut le `BAT54S`** : le nœud commun (pin 3) réunit une cathode et une anode, ce qui est exactement ce qu'exige un clamp bidirectionnel.

```
   Pin 3 (K1 ; A2) ──► le SIGNAL
   Pin 1 (A1)      ──► GND     : conduit sous ≈ −0,24 V
   Pin 2 (K2)      ──► +3,3 V  : conduit au-dessus de ≈ 3,54 V
```

| Paramètre | Valeur ✅ |
|---|---|
| `VF` @ 1 mA | ≤ 320 mV |
| `VF` @ 10 mA | ≤ 400 mV |
| `IR` | **≤ 2 µA** @ 25 V |
| `VR` max | 30 V |
| `Cd` | ≤ 10 pF |
| Boîtier | SOT-23 |

⚠️ **Trois réserves** :
1. **Une résistance série en amont est obligatoire.** Sans elle, le courant de faute n'est limité que par la source.
2. ⚠️ **Clamper vers le rail sur lequel le signal repose, pas vers 3,3 V.** Une ligne Hall au repos est à **5 V** : un clamp vers 3,3 V conduirait **en régime établi** (0,33 mA par voie, ~2 mA pour six voies injectés dans le rail 3,3 V) et annulerait le seul intérêt d'avoir choisi une entrée tolérante 5,5 V. → clamp vers **`5V_MOT`**.
3. ⚠️ **2 µA de fuite** ne sont pas négligeables sur une entrée haute impédance. Sur une entrée ADC à source impédante, ça crée un offset — pas un problème sur une entrée logique.

**Alternative si l'on préfère une TVS à un clamp à diodes** : [`PESD5V0F1BL`](https://assets.nexperia.com/documents/data-sheet/PESD5V0F1BL.pdf) ✅ — bidirectionnelle, `VRWM` 5,5 V, `VBR` 6–10 V, `VCL` ≤ 15 V @ 2,5 A, **`Cd` 0,4 pF typ**, IEC ±10 kV, boîtier DFN1006 1,0 × 0,6 mm. ⚠️ Ne pas confondre avec la `PESD5V0S1BA/BB/BL`, dont la capacité est de **35–45 pF** — réservée aux entrées lentes.

---

# Y.3 Module ESP32 et son support

## Y.3.1 ✅ Ton brochage est bien celui d'une DevKitC V4 officielle

[Guide utilisateur ESP32-DevKitC V4](https://docs.espressif.com/projects/esp-dev-kits/en/latest/esp32/esp32-devkitc/user_guide.html)

Brochage officiel des deux rangées de 19 broches :

- **J2** : `3V3, EN, VP(IO36), VN(IO39), IO34, IO35, IO32, IO33, IO25, IO26, IO27, IO14, IO12, GND, IO13, D2(IO9), D3(IO10), CMD(IO11), 5V`
- **J3** : `GND, IO23, IO22, TX(IO1), RX(IO3), IO21, GND, IO19, IO18, IO5, IO17, IO16, IO4, IO0, IO2, IO15, D1(IO8), D0(IO7), CLK(IO6)`

**Ta transcription correspond exactement à ces deux listes, lues dans l'autre sens.** Ton module est donc une **ESP32-DevKitC V4 38 broches** au brochage officiel Espressif — c'est une bonne nouvelle : le brochage est documenté et stable.

## Y.3.2 ⚠️ Entraxe : 25,40 mm, pas 22,86 mm

[Plan coté officiel ESP32-DevKitC V4](https://dl.espressif.com/dl/schematics/esp32_devkitc_v4_dimensions.pdf)

| Cote | Valeur ✅ |
|---|---|
| Carte | **48,26 × 27,94 mm** (1,900" × 1,100") |
| **Entraxe entre les deux rangées** | **25,40 mm = 1,000 pouce**, d'axe à axe |
| Pas dans une rangée | 2,54 mm |
| Largeur du module WROOM | 18,0 mm (c'est la cote `18.00` du plan — **pas** une cote de connecteur) |

⚠️ **Le README `motor_interface` annonce 22,86 mm.** C'est l'entraxe des cartes **tierces 30 broches**, qu'**Espressif ne documente pas du tout**. Un PCB percé à 22,86 mm n'acceptera jamais une DevKitC V4.

🔴 **Réserve honnête** : le plan Espressif ne **légende** aucune cote. Le 25,40 est établi par géométrie (27,94 de large, rangées à 1,27 mm de chaque bord) et par élimination (18,00 = largeur module). → **Mesure P1 au pied à coulisse sur ton exemplaire, avant de percer.** C'est deux minutes et ça évite cinq PCB inutilisables.

## Y.3.3 Broches de strapping — la liste officielle

[Datasheet ESP32 Series v5.3, §3](https://documentation.espressif.com/esp32_datasheet_en.pdf) · [esptool Boot Mode Selection](https://docs.espressif.com/projects/esptool/en/latest/esp32/advanced-topics/boot-mode-selection.html)

**Exactement cinq broches** ✅ :

| Broche | Pull interne par défaut ✅ | Rôle | Conséquence d'un mauvais niveau |
|---|---|---|---|
| `GPIO0` | **pull-up** | 1 = boot flash, 0 = bootloader série | Un pull-down externe force le mode téléchargement |
| `GPIO2` | **pull-down** | doit être 0 ou flottant pour entrer en download boot | Sans effet en boot normal |
| **`GPIO12` (MTDI)** | **pull-down** | **Sélection de `VDD_SDIO`** : 0 = 3,3 V, 1 = **1,8 V** | ⚠️ **BOOT IMPOSSIBLE.** Verbatim esptool : *« If driven High, flash voltage (VDD_SDIO) is 1.8 V not default 3.3 V […] may prevent flashing and/or booting if 3.3 V flash is used and this pin is pulled high, causing the flash to brownout. »* |
| `GPIO15` (MTDO) | **pull-up** | 1 = log de boot ROM sur U0TXD, 0 = silencieux | Non bloquant |
| `GPIO5` | **pull-up** | avec MTDO, timing SDIO slave | 🔴 Aucune conséquence documentée hors mode SDIO slave |

Timing : `tSU` min 0 ms, **`tH` min 1 ms** après `CHIP_PU` haut avant que les broches redeviennent des GPIO normaux ✅.

⚠️ **La règle absolue pour ton PCB : aucun pull-up externe sur `GPIO12`, jamais.** Le dossier §G.3 y assigne le PWM du ventilateur 1 sur le nœud SAFETY. Une LED de debug vers 3,3 V ou une résistance de tirage sur cette ligne rend le module **définitivement non démarrable**, avec un symptôme muet et déroutant. → **Recommandation : ne pas utiliser `GPIO12` du tout.** Il reste assez de broches.

Espressif ajoute deux règles de schéma ✅ :
- *« It is recommended to place a pull-up resistor at the GPIO0 pin »*
- *« Do not add high-value capacitors at GPIO0, or the chip may enter download mode »*
- Un bouton de boot exige un **pull-down fort, 10 kΩ vers GND** (le pull-up interne fait 45 kΩ)

## Y.3.4 Broches interdites et entrées seules

| Contrainte | Détail ✅ |
|---|---|
| **Flash SPI intégrée** | `GPIO6`=CLK, `GPIO7`=SD0, `GPIO8`=SD1, `GPIO9`=SD2, `GPIO10`=SD3, `GPIO11`=CMD. Sur le module WROOM elles **ne sont pas sorties** (broches NC), mais ⚠️ **la DevKitC les amène quand même sur ses connecteurs** sous les noms `D0`–`D3`, `CMD`, `CLK`. → **Aucune connexion sur ton PCB**, sérigraphie `NC — FLASH` |
| **PSRAM** | Sur les variantes `ESP32-D0WDR2-V3`, **`IO16` est reliée à la PSRAM et inutilisable** ✅. ESP-IDF ajoute `GPIO16-17` à la liste noire pour ces variantes. ⚠️ Le dossier §G.3 utilise `GPIO16/17` pour l'UART BMS et les straps de rôle → **vérifier la variante exacte de tes modules** |
| **Entrées seules, sans pull interne** | `GPIO34` (VDET_1), `GPIO35` (VDET_2), `GPIO36` (SENSOR_VP), `GPIO39` (SENSOR_VN) ✅. Pull-up ou pull-down **externe obligatoire** — 📐 **sauf** si la broche est pilotée en **push-pull** par un composant présent en permanence, ce qui est le cas des sorties du `SN74LVC3G17` |
| `GPIO37` / `GPIO38` | **Non sorties** sur WROOM-32 ✅ (absentes de la table de brochage du module) |
| **ADC2 / Wi-Fi** | *« ADC2 pins cannot be used when Wi-Fi is used »* ✅ — sans objet ici, Wi-Fi désactivé |
| Interruptions | *« do not use the interrupt of GPIO36 and GPIO39 when using ADC or Wi-Fi and Bluetooth with sleep mode enabled »* ✅ |

⚠️ **Point de conception** : une entrée `/SAFE` sur `GPIO34-39` sans pull externe **flotte**. Sur le signal le plus critique du robot, c'est un défaut de sécurité, pas un désagrément.

## Y.3.5 Alimentation, découplage, antenne

[Datasheet ESP32-WROOM-32E](https://documentation.espressif.com/esp32-wroom-32e_esp32-wroom-32ue_datasheet_en.pdf) · [Hardware Design Guidelines](https://docs.espressif.com/projects/esp-hardware-design-guidelines/en/latest/esp32/pcb-layout-design.html)

| Point | Exigence Espressif ✅ |
|---|---|
| Tension | 3,0 – 3,6 V, typ 3,3 V |
| **Courant de l'alimentation** | `IVDD` **min 0,5 A** — c'est une **exigence sur l'alimentation**, pas la consommation du module. Verbatim : *« the recommended power supply voltage is 3.3 V and the output current is no less than 500 mA »* |
| **RC sur `EN`** | *« R = 10 kΩ and C = 1 µF »*, à ajuster selon la séquence de montée |
| Entrée d'alimentation | *« add an ESD protection diode and at least 10 µF capacitor at the main power entrance »* |
| Broches d'alimentation numériques | *« add a 0.1 µF capacitor close to the digital power supply pins »* |
| **Nombre de couches** | *« It is recommended to use a four-layer PCB design »* : L1 signal, **L2 plan de masse intégral**, L3 alimentation, L4 quelques signaux |
| Plan de masse | *« at least nine ground vias »* sous le pavé de masse ; *« ground pads […] should make full contact with the ground copper pour rather than being connected via traces »* |
| **Placement du module** | *« It is suggested to place the module's on-board PCB antenna outside the base board, and the feed point of the antenna close to the edge »*. Sinon : *« cut off the base board on both sides of the antenna and below it »*. ⚠️ *« the module should not be placed in the center of the board »* |
| Autour de l'antenne | ⚠️ Nuance importante : Espressif ne dit **pas** « pas de cuivre près de l'antenne ». Il dit l'inverse pour la zone environnante — *« sufficient ground copper and dense ground vias should be placed on the base board near the antenna »*. **La règle est : évider sous le corps de l'antenne (ou la faire déborder), et entourer ce vide de cuivre de masse maillé de vias.** |
| Pistes RF | *« Do not route any traces under the RF trace »* ; *« The RF trace should be routed on the outer layer without vias »* |

🔴 **Non publié** : aucune cote numérique de zone d'exclusion d'antenne sur carte porteuse — Espressif ne la donne que graphiquement (fig. 23–24). Le seul chiffre publié est **15 mm de dégagement dans toutes les directions** à l'intérieur du boîtier du produit fini.

🔴 **Non publié** : aucune valeur de découplage pour la broche `3V3` **du module**. Le schéma « Peripheral Schematics » montre un 10 µF. 📐 Appliquer 10 µF + 0,1 µF au support est une extrapolation raisonnable du guide au niveau puce, pas une règle citée.

## Y.3.6 TWAI (CAN) sur ESP32

[ESP-IDF TWAI](https://docs.espressif.com/projects/esp-idf/en/latest/esp32/api-reference/peripherals/twai.html)

- ✅ Transceiver externe **obligatoire** : *« The ESP32 does not integrate an internal TWAI transceiver. »*
- ✅ Quatre lignes : `TX`, `RX`, `BUS_OFF`, `CLKOUT`, routables par la GPIO Matrix.
- 🔴 **Espressif ne publie aucune liste de GPIO autorisés ou interdits** pour TWAI — vérifié sur les versions *latest*, v5.3.1 et v4.4.8. La seule contrainte réelle (`TX` doit être une broche capable de sortie, donc **pas `GPIO34-39`**) vient du chapitre GPIO, pas du chapitre TWAI. À traiter comme une déduction, pas comme une citation.
- ✅ `TX` et `RX` peuvent être pontés pour un test de bouclage mono-nœud sans transceiver — pratique en recette.

---

# Y.4 Chaîne moteur
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

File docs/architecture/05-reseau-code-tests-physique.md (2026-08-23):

# O. Réseau et accès distant

## O.1 Principe : le graphe ROS 2 ne traverse pas le lien radio

C'est la décision structurante de cette section, et elle mérite d'être justifiée.

Le réflexe naturel est de mettre le poste opérateur et le robot sur le même `ROS_DOMAIN_ID` et de lancer RViz. Ça marche — sur un réseau filaire. Sur du Wi-Fi, ça se dégrade de façon pénible et non déterministe :

- **La découverte DDS repose sur du multicast UDP.** Le multicast 802.11 est émis au **débit de base le plus bas** et **sans acquittement** : taux de perte élevé, pas de retransmission. Les points d'accès grand public font de l'IGMP snooping, du multicast-to-unicast, ou droppent purement. L'isolation client casse tout.
- **Le trafic de découverte croît de façon quadratique** avec le nombre de participants.
- **Un topic RELIABLE avec un historique profond sur un lien lossy sature le canal en retransmissions**, et écroule tout le reste — y compris le lien SSH avec lequel on essaie de diagnostiquer.

Symptômes classiques : `ros2 topic list` incomplet, nœuds qui apparaissent 30 s plus tard, TF qui saute, RViz qui ne s'abonne jamais.

**Architecture retenue** :

```
   ╔═══════════════════════════════════════════════════════════════════╗
   ║  ZONE 3 — POSTE OPÉRATEUR                                         ║
   ║    Foxglove Studio (WebSocket)  ·  navigateur  ·  SSH             ║
   ║    RViz2 (uniquement en mode « atelier », voir O.5)               ║
   ╚═══════════════════════════════════╤═══════════════════════════════╝
                                       │  WireGuard — UDP 51820
                                       │  clés Curve25519, aucun mot de passe
   ╔═══════════════════════════════════▼═══════════════════════════════╗
   ║  ZONE 2 — SERVICES EXPOSÉS DU ROBOT (interface wg0 uniquement)    ║
   ║    :22    SSH (clés seulement, mot de passe désactivé)            ║
   ║    :8765  foxglove_bridge (WebSocket)                             ║
   ║    :8080  page d'état HTTP en lecture seule                       ║
   ║    ── nftables : DROP par défaut sur wlan0/eth0 ──                ║
   ╚═══════════════════════════════════╤═══════════════════════════════╝
                                       │
   ╔═══════════════════════════════════▼═══════════════════════════════╗
   ║  ZONE 1 — RÉSEAU INTERNE DU ROBOT (loopback + CAN)                ║
   ║    Graphe ROS 2 COMPLET, confiné à localhost                      ║
   ║    ROS_AUTOMATIC_DISCOVERY_RANGE=LOCALHOST                        ║
   ║    can0 — bus temps réel                                          ║
   ╚═══════════════════════════════════════════════════════════════════╝
```

**Le graphe ROS 2 est entièrement local.** Le pont vers l'extérieur est un **WebSocket** (`foxglove_bridge`), qui se reconnecte tout seul quand le lien tombe et remonte, et qui ne dépend pas de la découverte DDS.

⚠️ **Un lien radio marginal casse un graphe DDS. Il ne casse pas un WebSocket.** C'est la raison principale de ce choix.

## O.2 Configuration DDS

```bash
# /etc/retriever/ros-env.sh — chargé par tous les services
export ROS_DOMAIN_ID=42
export ROS_AUTOMATIC_DISCOVERY_RANGE=LOCALHOST   # découverte confinée à localhost
export RMW_IMPLEMENTATION=rmw_fastrtps_cpp       # défaut Jazzy, Tier 1
export ROS_LOCALHOST_ONLY=0                      # déprécié, on utilise DISCOVERY_RANGE
```

`ROS_AUTOMATIC_DISCOVERY_RANGE` (valeurs : `OFF` | `LOCALHOST` | `SUBNET` (défaut) | `SYSTEM_DEFAULT`) et `ROS_STATIC_PEERS` sont disponibles depuis Iron, donc sur Jazzy, et sont **indépendants du RMW** ✅. C'est la solution portable, sans XML vendeur.

### Si on veut vraiment étendre le graphe (mode atelier, §O.5)

```bash
# Robot 192.168.1.10 / poste 192.168.1.20 — DÉCOUVERTE 100 % UNICAST
export ROS_AUTOMATIC_DISCOVERY_RANGE=LOCALHOST
export ROS_STATIC_PEERS="192.168.1.20"    # (et l'inverse côté poste)
```

### `rmw_zenoh` — à évaluer, pas à déployer d'emblée

`ros-jazzy-rmw-zenoh-cpp` est **packagé et disponible en apt depuis janvier 2025** ✅, et les mainteneurs écrivent explicitement recommander son usage sur Jazzy et Rolling (« *feature complete and extensively tested* »). Son modèle — connexions unicast TCP/QUIC explicites entre routeurs, multicast désactivé par défaut — est **structurellement le bon** pour un lien radio. Un retour terrain publié rapporte un flux caméra 60 Hz passant de ~33 Hz saccadés (Fast DDS) à 59,5 Hz fluides (Zenoh) sur Jazzy.

**Mais** : il n'est **Tier 1 qu'à partir de Kilted**, pas sur Jazzy ✅. Et deux pièges documentés :
- **la configuration IPv6 par défaut fait planter le routeur sur un système IPv4-only** — piège classique en embarqué ;
- panics possibles à l'arrêt (timing de destruction du contexte).

📐 **Recommandation** : garder `rmw_fastrtps_cpp` + WebSocket comme architecture de référence, et évaluer `rmw_zenoh` en phase 3 avec un test A/B sur le lien réel, en injectant de la perte de paquets (`tc netem`). Si le résultat est bon, c'est un basculement d'une variable d'environnement.

## O.3 VPN

**WireGuard**, pour trois raisons : dans le noyau (performant), sans état (survit à un changement de réseau — 4G ↔ Wi-Fi), et configuration triviale.

```ini
# /etc/wireguard/wg0.conf (côté robot)
[Interface]
Address = 10.42.0.1/24
ListenPort = 51820
PrivateKey = <clé robot>

[Peer]                       # poste opérateur
PublicKey = <clé poste>
AllowedIPs = 10.42.0.2/32
PersistentKeepalive = 25
```

⚠️ **Le keepalive de 25 s sert aussi de détection de perte de lien** : `mission_manager` surveille l'état du peer WireGuard (`wg show`) et déclenche la politique de perte réseau (§M.2, panne 8).

## O.4 Pare-feu

```
nftables — politique par défaut : DROP en entrée

Sur wlan0 / eth0 :
  ✅ UDP 51820  (WireGuard)  — le SEUL port ouvert
  ✅ ICMP echo (diagnostic)
  ❌ TOUT le reste, y compris SSH

Sur wg0 :
  ✅ TCP 22    SSH
  ✅ TCP 8765  foxglove_bridge
  ✅ TCP 8080  page d'état
  ❌ DDS (7400-7500) — bloqué explicitement, même sur le VPN

Sortant : autorisé (NTP, mises à jour) — restreignable en exploitation
```

**SSH** : authentification par clé uniquement (`PasswordAuthentication no`, `PermitRootLogin no`), écoute sur `wg0` uniquement (`ListenAddress 10.42.0.1`).

⚠️ **Pourquoi bloquer DDS même sur le VPN** : parce que la tentation d'étendre le graphe « juste pour ce test » est forte, et que ça finit par rester. Le blocage explicite oblige à un geste conscient (§O.5).

## O.5 Les trois modes réseau

| Mode | Découverte | Pont | Usage |
|---|---|---|---|
| **TERRAIN** (défaut) | `LOCALHOST` | Foxglove WebSocket + SSH sur VPN | Exploitation normale |
| **ATELIER** | `LOCALHOST` + `ROS_STATIC_PEERS` vers le poste, DDS ouvert sur wg0 | RViz2 natif, `ros2 topic echo`, `rqt` | Développement, filaire de préférence |
| **AUTONOME** | `LOCALHOST` | Aucun | Aucun réseau. Le robot fonctionne seul. |

Le basculement se fait par une variable dans `/etc/retriever/network-mode` et un redémarrage du service. **Le mode ATELIER n'est jamais le mode par défaut.**

## O.6 Politique de perte de réseau

⚠️ **C'est une décision d'exploitation, pas une décision technique.** Je propose une politique et il faut l'assumer explicitement :

| Situation | Politique retenue 📐 | Justification |
|---|---|---|
| Mission **autonome** en cours, réseau perdu | ✅ **La mission continue** | Le robot est conçu pour être autonome. S'arrêter au milieu d'un champ hors de portée radio est pire que finir la mission. Un bag complet est activé automatiquement. |
| Mission **téléopérée**, réseau perdu | ❌ **`STOPPING` immédiat** (500 ms) | Une téléopération sans opérateur n'a aucun sens |
| Réseau perdu > 5 min en mission autonome | 🟡 **Retour au point de départ** | Limite de sécurité |
| Réseau perdu au démarrage | ✅ Le robot démarre quand même, reste en `READY` | Permet un démarrage sans infrastructure |

⚠️ **Coupure des commandes distantes** : un service `/retriever/disable_remote` désactive `foxglove_bridge` et la téléop, en gardant SSH. Utile si on soupçonne un problème côté opérateur.

## O.7 Résumé des ports

| Port | Protocole | Interface | Rôle |
|---|---|---|---|
| 51820 | UDP | wlan0/eth0 | WireGuard — **seul port exposé** |
| 22 | TCP | wg0 | SSH par clé |
| 8765 | TCP | wg0 | foxglove_bridge |
| 8080 | TCP | wg0 | Page d'état HTTP (lecture seule) |
| 7400-7500 | UDP | ❌ bloqué partout | DDS |

---

# P. Organisation du code

## P.1 Arborescence

```
retriever/
├── README.md
├── docs/                              ← ce dossier d'architecture
│   ├── 00-index-A-B.md … 06-bom-fmea-schema-plan.md
│   ├── wiring/                        schémas, plans de câblage, photos
│   └── measurements/                  résultats des mesures M1–M12
│
├── ros2_ws/src/
│   ├── retriever_msgs/                ★ SOCLE : messages, services, actions
│   │   ├── msg/ SafetyState.msg PowerStatus.msg MotorStatus.msg
│   │   │        CellVoltages.msg SelftestReport.msg MissionState.msg
│   │   ├── srv/ RequestArm.srv ClearFault.srv RunSelftest.srv
│   │   └── action/ RunMission.action
│   │
│   ├── retriever_can/                 ★ SOCLE : protocole CAN partagé
│   │   ├── protocol.yaml              ◄── SOURCE UNIQUE DE VÉRITÉ
│   │   ├── scripts/generate.py        → protocol.hpp (C++) + protocol.h (C)
│   │   ├── include/retriever_can/     (généré, versionné)
│   │   └── test/                      tests d'encodage/décodage
│   │
│   ├── retriever_description/         URDF/Xacro, meshes, TF statiques
│   │   ├── urdf/ retriever.urdf.xacro base.xacro wheels.xacro sensors.xacro
│   │   │         ros2_control.xacro   ← plugin réel OU mock, par argument
│   │   ├── config/ physical_params.yaml   ◄── UNE SEULE définition des dimensions
│   │   └── meshes/
│   │
│   ├── retriever_hardware/            Plugin ros2_control SystemInterface
│   │   ├── src/retriever_system.cpp
│   │   ├── retriever_hardware_plugin.xml
│   │   └── test/ test_can_loopback.cpp
│   │
│   ├── retriever_bringup/             ★ Point d'entrée unique
│   │   ├── launch/
│   │   │   ├── retriever.launch.py    ← LE fichier maître (arguments)
│   │   │   ├── hardware.launch.py
│   │   │   ├── sensors.launch.py
│   │   │   ├── localization.launch.py
│   │   │   ├── navigation.launch.py
│   │   │   ├── supervision.launch.py
│   │   │   └── kinect.launch.py       ← isolé, jamais critique
│   │   ├── config/
│   │   │   ├── controllers.yaml  ekf_odom.yaml  ekf_map.yaml
│   │   │   ├── navsat.yaml  nav2_indoor.yaml  nav2_outdoor.yaml
│   │   │   ├── collision_monitor.yaml  twist_mux.yaml
│   │   │   └── diagnostics_analyzers.yaml
│   │   └── systemd/ retriever-can.service  retriever-bringup.service
│   │
│   ├── retriever_can_bridge/          CAN ↔ topics ROS
│   ├── retriever_safety_bridge/       Miroir de la FSM sécurité
│   ├── retriever_power_monitor/       Batterie, énergie, historique SQLite
│   ├── retriever_selftest/            Pipeline de diagnostic §K
│   ├── retriever_mission/             mission_manager
│   ├── retriever_drivers/             Wrappers de lancement des drivers tiers
│   ├── retriever_sim/                 Gazebo, mondes, ros2_control mock
│   └── retriever_bench/               Outils de test, HIL, analyse de bags
│
├── firmware/
│   ├── common/
│   │   ├── protocol.h                 (généré depuis protocol.yaml)
│   │   ├── can_driver.c/h
│   │   ├── watchdog.c/h
│   │   └── safety_limits.h            ◄── constexpr, NON modifiables par CAN
│   ├── esp32_safety/     platformio.ini  src/main.c  src/fsm.c  src/bms.c …
│   ├── esp32_motion/     platformio.ini  src/main.c  src/pi.c  src/hall.c …
│   └── test/                          tests unitaires hôte (Unity/Ceedling)
│
├── tools/
│   ├── flash_all.sh                   Flashe les 3 ESP32, vérifie les versions
│   ├── check_protocol_sync.py         ⚠️ CI : firmware ↔ ROS cohérents ?
│   ├── calibrate_wheels.py
│   ├── analyze_bag.py
│   └── thermal_check.md               Procédure de thermographie
│
├── .github/workflows/ci.yml           build + tests + vérif. de synchronisation
└── deploy/ ansible/                   Déploiement reproductible sur le X1
```

## P.2 Les quatre principes de cette organisation

### 1. Une source de vérité par donnée

| Donnée | Source unique | Consommateurs |
|---|---|---|
| Protocole CAN | `retriever_can/protocol.yaml` | Généré vers C++ et C |
| Dimensions du robot | `retriever_description/config/physical_params.yaml` | URDF, controllers.yaml, EKF, Nav2 |
| Limites de sécurité | `firmware/common/safety_limits.h` | Firmware uniquement — **jamais** dupliquées côté ROS |
| Paramètres de navigation | `retriever_bringup/config/nav2_*.yaml` | Nav2 |

⚠️ **La duplication de la définition des dimensions est le bug le plus fréquent des projets robotiques** : le rayon de roue est dans l'URDF *et* dans `controllers.yaml`, on en modifie un, l'odométrie devient fausse de 3 % et on cherche pendant deux jours. Ici, `physical_params.yaml` est lu par les deux.

### 2. Le firmware et le logiciel sont un seul projet

Un seul dépôt Git, un seul commit pour un changement de protocole. La CI vérifie que `protocol.h` est bien régénéré (`check_protocol_sync.py`). Le hash du fichier `protocol.yaml` est compilé dans le firmware et remonté dans le heartbeat, et l'auto-test [P3] refuse de démarrer en cas de divergence.

### 3. Un point d'entrée unique et paramétré

```bash
# Terrain, extérieur, navigation autonome
ros2 launch retriever_bringup retriever.launch.py

# Banc, mock hardware, sans capteurs réels
ros2 launch retriever_bringup retriever.launch.py use_mock_hardware:=true use_sensors:=false

# Simulation Gazebo
ros2 launch retriever_bringup retriever.launch.py use_sim:=true

# Intérieur avec SLAM
ros2 launch retriever_bringup retriever.launch.py environment:=indoor slam:=true

# Rejeu de bag
ros2 launch retriever_bringup retriever.launch.py use_bag:=/path/to/bag
```

Arguments : `use_mock_hardware`, `use_sim`, `use_sensors`, `use_kinect`, `environment` (indoor/outdoor), `slam`, `nav`, `bench_mode`, `use_bag`, `log_level`.

### 4. Ce qui est critique est simple, ce qui est complexe n'est pas critique

| Critique (C1/C2) | Complexe |
|---|---|
| `firmware/` — quelques milliers de lignes de C, sans allocation dynamique | Nav2, `slam_toolbox` — paquets tiers matures |
| `retriever_hardware` — ~500 lignes | `retriever_mission` — logique métier |
| `retriever_can` — généré | `kinect2_ros2` — isolé, jamais dans le chemin critique |

## P.3 Séparation configuration / paramètres / code

| Catégorie | Où | Modifiable à chaud ? |
|---|---|---|
| **Limites de sécurité** | `firmware/common/safety_limits.h` | ❌ Jamais — recompilation |
| **Configuration matérielle** (broches, calibres) | `firmware/*/config.h` + `retriever_description/config/` | ❌ Non |
| **Paramètres d'algorithme** (gains, seuils Nav2) | YAML dans `retriever_bringup/config/` | ✅ Oui, via `ros2 param` |
| **Paramètres de mission** | YAML + arguments de lancement | ✅ Oui |
| **Réglages runtime** (vitesse max de mission) | Services ROS | ✅ Oui, avec saturation firmware |
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

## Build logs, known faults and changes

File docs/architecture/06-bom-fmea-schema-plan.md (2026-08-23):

# S. Nomenclature (BOM)

⚠️ **Les prix sont des ordres de grandeur 📐 (France, août 2026), à confirmer.** Aucune référence produit précise n'est donnée quand je ne peux pas la vérifier ; à la place, je donne les **caractéristiques minimales à respecter**, ce qui est plus durable qu'une référence qui sera obsolète.

## S.1 Déjà possédé

| Élément | Qté | Fonction | Remarque |
|---|---:|---|---|
| Youyeetoo X1 SBC | 1 | Calculateur ROS 2 | ⚠️ Wiki officiel documente Ubuntu 22.04 ; 24.04 à valider |
| Batterie Xiaomi M365 | 1 | Source d'énergie | ⚠️ Courant max inconnu — **mesure M1** |
| ZS-X11H | 4 | Variateurs BLDC | ⚠️ **Mesures M4, M5, M12** avant tout branchement |
| Moteur-roue hoverboard 6,5" | 4 | Traction | 🔴 Non listés dans le matériel initial — **à confirmer que tu les as** |
| ESP32 | ≥3 | Contrôleurs temps réel | 🔴 **Question Q5** : modèle exact ? |
| YDLIDAR X4 | 1 | Lidar 2D | ❌ Intérieur uniquement |
| Kinect v2 | 1 | RGB-D | ❌ Intérieur uniquement, ⚠️ **mesure M9** |
| BNO085 | 1 | IMU 9 axes | ✅ Bon choix, à monter en SPI |
| GPS USB | 1 | Position absolue | 🔴 **Question Q4** : référence ? |
| ACS758LCB-100B | 1 | Mesure de courant | 🟡 Réaffecté à la protection, pas au SOC |
| Ventilateur PWM 12 V | 2 | Refroidissement | ✅ |
| Disjoncteur 100 A | 1 | — | ❌ **Non utilisé** — voir §D.3 |
| Coupe-batterie | 1 | Sectionnement | 🔴 **À caractériser** : est-il DC-rated ≥48 V ? Sinon → à remplacer |

## S.2 À acheter impérativement

Sans ces éléments, le robot ne peut pas être construit en sécurité.

### Protection et coupure

| Élément | Qté | Fonction | Spécification minimale | Prix 📐 | Où |
|---|---:|---|---|---:|---|
| Fusible MRBF + porte-fusible sur borne | 1 | Protection principale | **80 A, ≥58 V DC, AIC ≥2000 A @58 V** | 35 € | Marine/nautique |
| Fusibles MIDI 58 V + porte-fusibles | 4 | Protection variateurs | **25 A, ≥58 V DC** | 30 € | Marine/auto |
| Fusible MIDI 58 V + porte-fusible | 1 | DC/DC compute | **10 A, ≥58 V DC** | 8 € | idem |
| Fusible MIDI 58 V + porte-fusible | 2 | DC/DC aux + alim SAFETY | **5 A et 2 A, ≥58 V DC** | 14 € | idem |
| Sectionneur DC | 1 | Coupe-batterie | **≥48 V DC, ≥150 A continu**, rotatif à clé, corps étanche | 50 € | Marine |
| Contacteur / relais DC | 1 | Coupure commandée | **NO, ≥48 V DC, ≥100 A**, bobine 12 V | 45 € | Marine/auto/EV |
| **Champignon d'arrêt d'urgence** | 1 | Arrêt d'urgence | **Contact NF**, accrochage mécanique, Ø ≥40 mm, IP65 | 20 € | Électricité industrielle |
| Interrupteur à clé 2 positions | 1 | BANC/TERRAIN | 2 contacts NO, IP65 | 15 € | idem |
| Bouton poussoir « mise sous puissance » | 1 | Démarrage | NO, IP65, lumineux | 12 € | idem |

⚠️ **Rien de cette liste ne s'achète en GSB.** Ce sont des composants DC dont le pouvoir de coupure et la tension assignée en continu sont déclarés — c'est exactement ce qui manque au matériel de tableau domestique.

### Distribution

| Élément | Qté | Fonction | Spécification | Prix 📐 | Où |
|---|---:|---|---|---:|---|
| Barre cuivre Cu-ETP **étamée** 20 × 3 mm | 0,5 m | Busbars | **C11000, étamage ≥12,7 µm** | 30 € | Fournisseur électrique / Farnell / RS |
| Boulonnerie M6 acier 8.8 zingué | 20 | Fixation busbar | Tête hexa + écrou | 8 € | GSB ✅ |
| **Rondelles Belleville M6** | 20 | ⚠️ Compensation du fluage du cuivre | Acier ressort | 10 € | Fournisseur industriel |
| Rondelles plates larges M6 | 40 | Répartition | Inox ou acier zingué | 5 € | GSB ✅ |
| Entretoises isolantes PA6/POM 15 mm | 8 | Séparation des barres | M6 | 10 € | GSB ✅ |
| Plaque polycarbonate 3 mm | 0,25 m² | Capots busbar | Transparent | 15 € | GSB ✅ |

### Câblage

| Élément | Qté | Spécification | Prix 📐 | Où |
|---|---:|---|---:|---|
| Câble souple **cuivre étamé** 25 mm² rouge + noir | 2 × 1,5 m | Classe 5, isolant 105 °C, ISO 6722 ou marine | 45 € | Marine/auto |
| Câble souple étamé 6 mm² rouge + noir | 2 × 6 m | idem | 55 € | idem |
| Câble souple 2,5 / 1,5 / 1,0 mm² multicolore | 5 m chacun | Souple, 105 °C | 35 € | idem/GSB |
| Paire torsadée blindée 2 × 0,34 mm² + 2 × 0,5 | 5 m | CAN + alimentation | 15 € | Électronique |
| Câble blindé 5 × 0,25 mm² | 4 m | Hall | 12 € | idem |
| Cosses à œil M6 cuivre étamé 25 mm² | 6 | Sertissage | 12 € | Marine |
| Cosses à œil M6 cuivre étamé 6 mm² | 20 | idem | 18 € | idem |
| Cosses Faston isolées 6,3 mm | 24 | Phases moteur | 10 € | Auto |
| **Gaine thermorétractable double paroi à colle** | Assortiment | Étanchéité des cosses | 25 € | Marine/électronique |
| **Pince à sertir hydraulique 16 t** | 1 | ⚠️ **Sertissage 6 et 25 mm²** | 80 € | Outillage |
| Connecteurs Anderson SB50 rouge | 2 paires | Batterie | 25 € | Marine/auto |
| Connecteurs Molex Micro-Fit 4 pos | 10 | Bus CAN | 15 € | Électronique |
| Connecteurs JST-XH / PH assortis | lot | Capteurs, signaux | 20 € | Électronique |

### Électronique

| Élément | Qté | Fonction | Spécification | Prix 📐 |
|---|---:|---|---|---:|
| **Adaptateur USB-CAN gs_usb / candleLight** | 1 | Passerelle CAN | ⚠️ **Firmware candleLight/gs_usb impératif** (SocketCAN natif) | 30 € |
| Transceiver CAN SN65HVD230 / TCAN332 | 3 | Interface ESP32 ↔ CAN | 3,3 V | 12 € |
| DC/DC 36→12 V **isolé** | 1 | Rail COMPUTE | **In 20–60 V, out 12 V / 8 A, isolé, rendement ≥90 %** | 40 € |
| DC/DC 36→12 V | 1 | Rail AUX | In 20–60 V, out 12 V / 5 A | 20 € |
| DC/DC 12→5 V | 1 | Rail LOGIC | Out 5 V / 5 A | 12 € |
| DC/DC 36→5 V petit | 1 | Alim ESP32-SAFETY **amont contacteur** | In 20–60 V, out 5 V / 1 A | 10 € |
| MCP4728 (DAC 4 ch 12 bits I²C) | 2 | Consigne VR | | 12 € |
| AOP rail-to-rail double, alim 5 V | 2 | Ampli 0–3,3 → 0–5 V | MCP6002 ou équivalent | 5 € |
| ADS1115 (ADC 16 bits I²C) | 1 | ACS758 + tensions | | 8 € |
| 74LVC245 | 2 | Adaptation Hall 5 V → 3,3 V | Entrées 5 V tolérantes | 4 € |
| Isolateur numérique ADuM1201 | 1 | Liaison BMS | 2 canaux, ≥1 Mbit/s | 8 € |
| **Watchdog externe TPL5010** ou équivalent | 1 | Surveillance ESP32-SAFETY | Période ~1 s, sortie reset | 6 € |
| Résistance bobinée 10 Ω / 25 W | 1 | Précharge | ⚠️ **Tenue impulsionnelle ≥50 J** | 8 € |
| Relais signal 12 V / 10 A | 1 | Précharge | | 5 € |
| TVS 5KP45A ou 5KP48A | 1 | Bus | Unidirectionnel, **V_standoff > 42 V** | 4 € |
| TVS SMCJ45A ou SMCJ48A | 4 | Entrée variateur | Unidirectionnel, V_standoff > 42 V | 5 € |
| Condensateurs 470 µF / 63 V low-ESR | 4 | Filtrage variateur | ⚠️ **63 V minimum** | 12 € |
| MOSFET 2N7002 + résistances | lot | Sorties collecteur ouvert | | 6 € |
| NTC 10 kΩ + câbles | 3 | Températures | | 8 € |
| LED RGB haute luminosité + buzzer | 1 | Signalisation | | 10 € |
| LED rouge + résistance 10 kΩ / 1 W | 1 | ⚠️ Témoin « bus sous tension » | | 2 € |
| Hub USB 3.0 **alimenté** | 1 | Extension USB | Alimentation externe 5 V obligatoire | 25 € |
| Ferrites à clipser | lot | Filtrage USB/CAN | | 12 € |

### Mécanique et coffret

| Élément | Qté | Spécification | Prix 📐 | Où |
|---|---:|---|---:|---|
| Coffret IP65 + rail DIN | 1–2 | Selon volume | 40 € | GSB ✅ |
| Presse-étoupes M16/M20/M25 | 12 | ⚠️ Vérifier la plage pour le 25 mm² | 20 € | GSB ✅ |
| Plaque alu 3–5 mm | 0,2 m² | Dissipateur variateurs | 30 € | GSB ✅ |
| Pâte thermique | 1 | | 8 € | Informatique |
| Sangles + mousse EVA | — | Fixation du pack | 20 € | GSB ✅ |
| Gaine annelée + colliers UV | lot | Cheminement | 25 € | GSB ✅ |
| Étiqueteuse thermorétractable ou étiquettes | 1 | Repérage | 30 € | Électricité |

**Sous-total impératif : ≈ 1 090 €** 📐

## S.3 À acheter recommandé

Améliore fortement la sécurité, la fiabilité ou la maintenance.

| Élément | Qté | Fonction | Prix 📐 | Priorité |
|---|---:|---|---:|---|
| **Thermomètre infrarouge** | 1 | ⚠️ Contrôle des jonctions — **le meilleur rapport sécurité/prix du projet** | 30 € | ★★★ |
| **Extincteur classe D ou seau de sable sec** | 1 | Feu de lithium | 60 € | ★★★ |
| **Sac / caisse ignifuge LiPo** | 1 | Stockage du pack | 25 € | ★★★ |
| **Clé dynamométrique 2–25 N·m** | 1 | Couples de busbar reproductibles | 45 € | ★★★ |
| **Alimentation de laboratoire 0–60 V / 5 A à limitation de courant** | 1 | ⚠️ **Indispensable pour tous les tests de niveau 0 et 1** | 130 € | ★★★ |
| Pince ampèremétrique **DC** | 1 | Mesures de courant | 60 € | ★★ |
| Multimètre correct (True RMS, µA) | 1 | | 60 € | ★★ |
| Oscilloscope 2 voies ≥50 MHz | 1 | Mesures M3, M4, M7 ; debug CAN et PWM | 250 € | ★★ |
| E-stop **radio** (émetteur + récepteur, contact NF) | 1 | Arrêt d'urgence à distance | 90 € | ★★★ |
| SSD NVMe M.2 500 Go | 1 | Bags, cartes, système | 45 € | ★★ |
| Deuxième pack batterie compatible | 1 | Autonomie, redondance | ~90 € | ★★ |
| Chargeur 42 V / 2 A de qualité | 1 | | 30 € | ★★ |
| Antenne Wi-Fi déportée à gain | 2 | Portée | 25 € | ★ |
| Onduleur / alim de banc 12 V pour le X1 | 1 | Développement hors batterie | 25 € | ★★ |
| Roulettes folles + châssis de banc | 1 | Tests roues levées | 40 € | ★★ |

**Sous-total recommandé : ≈ 1 005 €** 📐 (dont ~440 € d'instrumentation réutilisable pour tous tes projets)

## S.4 Optionnel — améliorations futures

| Élément | Fonction | Prix 📐 | Phase |
|---|---|---:|---|
| **Lidar 2D extérieur IP65** (immunité solaire spécifiée) | Remplacement du X4 en extérieur | 400–1500 € | 4 |
| **GNSS RTK** (base + rover, ou abonnement NTRIP) | Précision 2–5 cm au lieu de 2–5 m | 300–600 € | 4 |
| **GNSS double antenne avec heading** | ⚠️ Résout le problème du cap (§N.3) | 400–800 € | 4 |
| Caméra stéréo extérieure | Remplacement du Kinect | 250–400 € | 4 |
| **Frein mécanique à manque de courant** ×2 | ⚠️ Tient une pente robot hors tension | 150 € | 4 |
| **Hacheur de freinage** (MOSFET + résistance de puissance) | Absorbe l'énergie de régénération | 40 € | 3–4 |
| Shunt 500 µΩ + INA228 | Mesure de courant à 0,1 % | 25 € | 3 |
| BMS de remplacement à seuils documentés | ⚠️ Lève l'incertitude M1 | 60 € | 3 |
| Pack batterie plus capacitaire (48 V, 20 Ah) | ⚠️ **Résout le problème de fond du §A.1-5** | 400 € | 4 |
| Variateurs BLDC pilotables (VESC, ODrive) | Contrôle en couple, télémétrie riche, freinage maîtrisé | 4 × 90 € | 4 |
| Caméra thermique smartphone | Diagnostic avancé | 250 € | 3 |
| Boîtier IP67 à refroidissement par conduction | Usage tout temps | 200 € | 4 |

## S.5 Résumé budgétaire

| Poste | Montant 📐 |
|---|---:|
| Impératif | 1 090 € |
| Recommandé | 1 005 € |
| **Total pour un robot sûr et instrumenté** | **≈ 2 100 €** |
| Optionnel (phase 4) | 1 500 – 4 000 € |

⚠️ **Répondant explicitement à la contrainte du cahier des charges** : les éléments critiques pour la sécurité (protections DC, sectionneur, cuivre, cosses, sertissage) **ne sont pas disponibles en grande surface de bricolage**, et là où ils semblent l'être (disjoncteur 100 A, fusibles à lame, dominos), le produit n'a pas les caractéristiques DC requises. **La sécurité électrique prime : ces éléments doivent venir de fournisseurs marine, automobile ou industriels.**

Ce que Leroy Merlin Mérignac fournit très bien : coffrets IP65, presse-étoupes, visserie, plaques polycarbonate et alu, gaines, colliers, entretoises, rail DIN, outillage. Soit environ **200 €** sur les 1 090 € impératifs.

---

# T. Analyse des risques (FMEA simplifiée)

**Échelles** — Probabilité : 1 = très improbable … 5 = fréquent · Gravité : 1 = négligeable … 5 = catastrophique (blessure, incendie) · Détection : 1 = détecté immédiatement … 5 = indétectable
**Criticité C = P × G × D** (max 125). Seuil d'action retenu : **C > 24** 📐

| # | Risque | P | G | D | **C** | Détection | Mitigation |
|---:|---|:-:|:-:|:-:|:-:|---|---|
| 1 | **Emballement thermique du pack Li-ion** | 2 | **5** | 3 | **30** | Température BMS, Δ cellules, odeur, gonflement | Surveillance BMS (T° + 10 cellules), seuils stricts, pack sanglé et isolé thermiquement, ventilation séparée, **stockage en sac ignifuge**, extincteur classe D, ⚠️ **historique du Δ cellules** |
| 2 | **Court-circuit franc du bus (kA)** | 2 | **5** | 1 | **10** | Fusible MRBF, chute de V_bus | MRBF 80 A / 58 V à ≤175 mm de la borne, AIC 2000 A, busbars **superposés et capotés**, aucune polarité nue |
| 3 | **Jonction dégradée → point chaud → incendie** | **4** | **5** | **4** | **80** ⚠️ | ⚠️ Difficile en direct. Signature : R apparente du bus qui augmente | ⚠️ **LE RISQUE N°1.** Rondelles Belleville, cuivre **étamé**, sertissage hydraulique, couple contrôlé + marque témoin, **recouple à 48 h / 6 mois**, **thermographie toutes les 50 h**, surveillance ΔV/ΔI |
| 4 | **Fusible à lame 32 V sur bus 42 V ne coupe pas** | 3 | **5** | 3 | **45** ⚠️ | Après coup (carbonisation) | ⚠️ **Aucun fusible ATO/MAXI sur le bus.** Uniquement MRBF/MIDI **58 V**. Les ATO 32 V restent admis **après** le DC/DC 12 V |
| 5 | **Arc entretenu sur connecteur desserré** | 3 | **5** | 4 | **60** ⚠️ | Odeur, bruit, thermographie | Reprise mécanique de tous les connecteurs, frein filet, contrôle visuel avant chaque sortie, connecteurs à forte pression (Anderson) |
| 6 | **Inversion de polarité** | 2 | 4 | 1 | **8** | Immédiate (rien ne fonctionne) | **Connecteurs détrompés + code couleur** (l'erreur devient physiquement impossible) |
| 7 | **Appel de courant sans précharge → contacts soudés** | 3 | 4 | 2 | **24** | Contacteur qui ne s'ouvre plus | Séquence de précharge obligatoire avec timeout, **détection de contacteur collé** (V_bus vs commande) |
| 8 | **BMS coupe en pleine manœuvre** | **4** | 3 | 2 | **24** | Perte totale immédiate | ⚠️ **Budget de courant 20 A / 30 A crête** appliqué par l'ESP32-SAFETY, mesure ACS758 à 500 Hz, bridage progressif dès 22 A. **Mesure M1 impérative** |
| 9 | **Surtension par freinage régénératif** | 3 | 4 | 2 | **24** | ACS758 négatif, V_bus > 43 V | Mesure bidirectionnelle, bridage du freinage au-dessus de 41 V, limite de décélération, ⚠️ raccordement BMS côté `P-` |
| 10 | **Les condensateurs des ZS-X11H sont en 50 V** | 3 | 4 | 2 | **24** | Inspection visuelle | ⚠️ **Mesure M12 avant toute mise sous tension.** Si 50 V → TVS + condensateurs 100 V, ou renoncer à charger le pack au-delà de 40 V |
| 11 | **Perte du X1 (crash, OOM, gel)** | **4** | 3 | 1 | **12** | Heartbeat matériel + CAN | Watchdogs N3/N4, arrêt en 300 ms. ⚠️ **Le X1 n'est pas le seul à pouvoir arrêter les moteurs** |
| 12 | **Perte d'un ESP32** | 3 | 3 | 1 | **9** | Heartbeat CAN | WDT interne + externe, état sûr au reset, `/SAFE` actif pendant le reset |
| 13 | **Bus CAN en défaut** | 3 | 3 | 1 | **9** | Compteurs CAN, bus-off | Paire torsadée blindée, terminaisons correctes, `restart-ms 100`, chaque nœud a son watchdog local |
| 14 | **Bug ROS 2 → commande dangereuse** | **4** | 4 | 3 | **48** ⚠️ | Plausibilité, limites firmware | ⚠️ **7 filtres successifs** (§L.2), limites `constexpr` firmware non contournables, CRC8 + numéro de séquence, budget de courant |
| 15 | **Fils de phase moteur inversés** | 3 | 3 | 1 | **9** | Test de sens de rotation [P5] | Test automatique roues levées, 4 s, à chaque boot en mode BANC |
| 16 | **Entrée VR flottante (fil coupé)** | 2 | **5** | 4 | **40** ⚠️ | ⚠️ Difficile : comportement indéfini | ⚠️ **Résistance 10 kΩ de rappel à la masse sur chaque entrée VR**, au plus près du variateur. Transforme la rupture en consigne nulle |
| 17 | **Moteur bloqué → surintensité → surchauffe** | 3 | 3 | 2 | **18** | Comptes Hall = 0 avec consigne ≠ 0 | Détection en 300 ms, coupure de la roue, fusible 25 A |
| 18 | **Perte du lidar en navigation** | 3 | 3 | 1 | **9** | `source_timeout` du collision monitor | Arrêt automatique, `DEGRADED`, vitesse plafonnée |
| 19 | **Covariance GPS nulle → EKF diverge** | 3 | 3 | **4** | **36** ⚠️ | ⚠️ Sournois : le robot part n'importe où | Test [P4] : covariance nulle = **FAIL**. Nœud de calcul depuis le HDOP si le driver ne la fournit pas |
| 20 | **Cap magnétique faux (perturbation moteur)** | **5** | 3 | **4** | **60** ⚠️ | ⚠️ Le robot navigue « bien » mais dans la mauvaise direction | ⚠️ **BNO085 sur mât ≥25 cm au-dessus des busbars**, calibration hard/soft iron, **initialisation du cap par le déplacement GPS**, évaluer Game Rotation Vector (dérive 0,5°/min) vs magnétomètre |
| 21 | **Patinage skid-steer → odométrie fausse** | **5** | 2 | 3 | **30** | Divergence odométrie/GPS | ⚠️ **Ne pas fusionner `vyaw` des roues** — utiliser le gyro. Étalonnage `wheel_separation_multiplier`. Fusion GPS |
| 22 | **Divergence firmware / logiciel** | **4** | 3 | 3 | **36** ⚠️ | Hash de protocole dans le heartbeat | ⚠️ `protocol.yaml` **source unique**, génération automatique, CI qui vérifie, refus d'armement en cas de divergence |
| 23 | **Champignon défaillant (contact oxydé)** | 2 | **5** | **5** | **50** ⚠️ | ⚠️ **Indétectable sans test actif** | ⚠️ **Test actif obligatoire à chaque session** [P6] : l'opérateur appuie, le système vérifie la transition. Contact **NF** (une rupture de fil = sécurité) |
| 24 | **Contacteur collé** | 2 | **5** | 3 | **30** | V_bus reste haute après commande d'ouverture | Détection [P6], alerte `CRITICAL`, buzzer continu, consigne d'ouvrir le coupe-batterie |
| 25 | **Bruit électrique → capteurs erratiques** | **4** | 2 | 3 | **24** | Valeurs aberrantes, erreurs CAN | Séparation des cheminements ≥10 cm, torsadage, blindage à un seul point, ferrites, DC/DC compute **isolé**, masse en étoile |
| 26 | **Alimentation instable → reboots** | 3 | 3 | 2 | **18** | Journaux, compteurs de reset | DC/DC dimensionnés ×2, condensateurs de découplage, rails surveillés par [P2] |
| 27 | **Robot en roue libre après coupure, en pente** | 3 | 4 | 2 | **24** | Observation | ⚠️ **Boucle e-stop à deux temps** : freinage électrique d'abord, contacteur ~1 s après. Évolution : frein mécanique à manque de courant |
| 28 | **Basculement du robot** | 2 | 3 | 2 | **12** | IMU : angle > 40° | Arrêt automatique, centre de gravité bas, garde au sol maîtrisée |
| 29 | **Perte réseau en téléopération** | **4** | 3 | 1 | **12** | Keepalive WireGuard | `STOPPING` en 500 ms |
| 30 | **Exposition de ROS 2 sur Internet** | 2 | 4 | 3 | **24** | Audit | ⚠️ **DDS confiné à localhost**, WireGuard seul port ouvert, nftables DROP par défaut, DDS bloqué même sur le VPN |
| 31 | **Disque plein → arrêt de la journalisation** | **4** | 2 | 2 | **16** | `diagnostic_common_diagnostics` | Rotation automatique, purge, `FAIL` à moins de 2 Go |
| 32 | **Le Kinect ne fonctionne pas (contrôleur ASMedia)** | 3 | 1 | 1 | **3** | Mesure M9 | Vérification avant toute intégration ; le Kinect n'est jamais critique |
| 33 | **Ubuntu 24.04 non supporté par le X1** | 2 | 4 | 1 | **8** | Test de boot | ⚠️ **À valider en tout premier (V1).** Repli : Ubuntu 22.04 + ROS 2 Humble, ou conteneur Docker Jazzy sur 22.04 |
| 34 | **Le driver YDLIDAR ne compile pas sur Jazzy** | 3 | 2 | 1 | **6** | Test de build | Pas de release binaire Jazzy ; build source depuis la branche `humble` (recommandation officielle YDLIDAR) |

## T.1 Les six risques prioritaires (C > 40)

| Rang | # | Risque | C | Action immédiate |
|---:|---:|---|:-:|---|
| **1** | 3 | Jonction dégradée → point chaud → incendie | **80** | Sertissage hydraulique + Belleville + étamage + couple contrôlé + **thermographie planifiée**. Non négociable. |
| **2** | 5 | Arc entretenu sur connecteur desserré | **60** | Reprise mécanique systématique, frein filet, inspection avant chaque sortie |
| **2** | 20 | Cap magnétique faux | **60** | Mât IMU ≥25 cm, calibration, init de cap par déplacement GPS |
| **4** | 23 | Champignon défaillant | **50** | Test actif obligatoire à chaque session |
| **5** | 14 | Bug ROS 2 → commande dangereuse | **48** | 7 filtres, limites firmware `constexpr`, budget de courant |
| **6** | 4 | Fusible 32 V sur bus 42 V | **45** | Aucun ATO/MAXI sur le bus. MRBF/MIDI 58 V uniquement |

⚠️ **Observation importante** : les deux risques les plus critiques (#3 et #5) sont des risques **de fabrication mécanique**, pas des risques logiciels. C'est contre-intuitif pour un projet perçu comme « robotique », mais c'est la réalité de tous les systèmes de puissance DC. **Le temps passé sur le sertissage et le serrage est plus rentable, en sécurité, que le temps passé sur l'architecture logicielle.**

---

# U. Schéma global final

```
╔══════════════════════════════════════════════════════════════════════════════╗
║                        POSTE OPÉRATEUR (distant)                             ║
║   Foxglove Studio (WebSocket:8765) · SSH · page d'état HTTP · manette         ║
╚═══════════════════════════════════╤══════════════════════════════════════════╝
                                    │  WireGuard UDP:51820  — seul port ouvert
                                    │  nftables DROP par défaut · DDS bloqué
╔═══════════════════════════════════▼══════════════════════════════════════════╗
║  YOUYEETOO X1 · Ubuntu 24.04 · ROS 2 Jazzy          [ NON TEMPS RÉEL ]        ║
║                                                                              ║
║  ┌─ SUPERVISION ──────────────────────────────────────────────────────────┐  ║
║  │ mission_manager · retriever_safety_bridge (MIROIR, sans autorité)      │  ║
║  │ retriever_power_monitor · retriever_selftest · diagnostic_aggregator   │  ║
║  │ foxglove_bridge · rosbag2 (buffer pré-défaut 60 s)                     │  ║
║  └────────────────────────────────────────────────────────────────────────┘  ║
║  ┌─ NAVIGATION ───────────────────────────────────────────────────────────┐  ║
║  │ Nav2 : planner · controller (MPPI + rotation_shim) · bt_navigator      │  ║
║  │ velocity_smoother → collision_monitor (VelocityPolygon) → twist_mux    │  ║
║  └────────────────────────────────────────────────────────────────────────┘  ║
║  ┌─ LOCALISATION ─────────────────────────────────────────────────────────┐  ║
║  │ ekf_odom (odom→base_link) · navsat_transform · ekf_map (map→odom)      │  ║
║  │ slam_toolbox (intérieur, phases 1–2 uniquement)                        │  ║
║  └────────────────────────────────────────────────────────────────────────┘  ║
║  ┌─ MATÉRIEL ─────────────────────────────────────────────────────────────┐  ║
║  │ controller_manager @100 Hz + retriever_hardware (SocketCAN)            │  ║
║  │   └ diff_drive_controller (4 roues : 2G / 2D)                          │  ║
║  │ retriever_can_bridge · drivers lidar / GPS / (Kinect)                  │  ║
║  └────────────────────────────────────────────────────────────────────────┘  ║
╚═══╤═══════════════════╤═══════════════════════════════════╤══════════════════╝
    │ USB 3.0 #1        │ USB 3.0 #2 → hub alimenté         │ GPIO
    │                   │   ├── YDLIDAR X4 (+5 V externe ⚠️) │ heartbeat 10 Hz
┌───▼────────┐          │   ├── GPS USB                     │ (indépendant du CAN)
│ Kinect v2  │          │   └── USB-CAN gs_usb              │
│ ⚠️ 12V/32W │          │        │                          │
│ secteur    │          │        ▼                          │
│ intérieur  │      ════╧════════╪══════ CAN 500 kbit/s ════╧═══════════════════
└────────────┘               ╤       ╤            ╤
                             │       │            │
            ┌────────────────▼──┐ ┌──▼─────────┐ ┌▼──────────────┐
            │  ESP32-SAFETY     │ │ESP32-MOT-AV│ │ESP32-MOT-AR   │
            │  ★ AUTORITÉ ★     │ │            │ │               │
            │  FSM sécurité 1kHz│ │ PI 200 Hz  │ │ PI 200 Hz     │
            │  alimenté EN AMONT│ │ ×2 roues   │ │ ×2 roues      │
            │  du contacteur    │ │            │ │               │
            └─┬──┬──┬──┬──┬──┬──┘ └──┬──┬──────┘ └──┬──┬─────────┘
              │  │  │  │  │  │       │  │           │  │
       BNO085 │  │  │  │  │  └ventilos│ └Hall×4     │  └Hall×4
        (SPI) │  │  │  │  └ACS758     └DAC+GPIO     └DAC+GPIO
   BMS UART ⚡┘  │  │  └V_bus/V_pack     │              │
   contacteur ───┘  │                    ▼              ▼
   précharge ───────┘              ZS-X11H ×2      ZS-X11H ×2
              │                          │              │
        ┌─────▼──────┐             Moteur-roue    Moteur-roue
        │ /SAFE ─────┼──────────────────► entrées EL + STOP des 4 variateurs
        │ (actif bas,│                    (sécurité positive)
        │  coll. ouv)│
        └────────────┘
   ┌──────────────────────┐
   │ 🔴 CHAMPIGNON (NF)   ├──► /SAFE directement (freinage immédiat)
   │                      ├──► bobine contacteur, via RC ~1 s
   │ ⏱ WATCHDOG TPL5010   ├──► reset ESP32-SAFETY + /SAFE
   └──────────────────────┘

╔══════════════════════════ CHAÎNE DE PUISSANCE ═══════════════════════════════╗
║                                                                              ║
║  ┌────────────┐  ① coupe-  ② MRBF   ③ ACS758  ④ CONTACTEUR                  ║
║  │ PACK M365  │   batterie   80 A     100 A      DC 100 A                   ║
║  │ 10S · 280Wh├──►  DC   ──► 58 V ──► bidir. ──►   NO    ──┬──► BUSBAR +     ║
║  │ 30–42 V    │    48 V     AIC2kA              ▲         │   Cu 20×3 étamé ║
║  │ BMS ⚡UART │                                  │         │   10 postes     ║
║  └────────────┘                        ⑤ précharge         │   2 libres      ║
║                                         10 Ω / 25 W        │                 ║
║                                         + timeout 1,5 s    │                 ║
║  ┌─────────┬─────────┬─────────┬─────────┬─────────┬───────┴─────┐           ║
║ MIDI25   MIDI25   MIDI25   MIDI25     MIDI10    MIDI5      MIDI2            ║
║  │         │         │         │         │         │           │            ║
║ ZS-X11H  ZS-X11H  ZS-X11H  ZS-X11H   DC/DC12V  DC/DC12V  DC/DC 5V           ║
║  AV-G     AV-D     AR-G     AR-D     COMPUTE     AUX     ★SAFETY★           ║
║  │         │         │         │      (isolé)     │      (amont             ║
║  ▼         ▼         ▼         ▼         │        ├─►ventilos contacteur)   ║
║ Moteur   Moteur   Moteur   Moteur      X1 +      ├─►bobine                  ║
║ 6,5"     6,5"     6,5"     6,5"       hub USB    └─►DC/DC 5V LOGIC          ║
║  │         │         │         │         │             │                    ║
║  └─────────┴─────────┴─────────┴─────────┴─────────────┴──► BUSBAR −         ║
║                                              = MASSE ÉTOILE UNIQUE          ║
║                                                                              ║
║  Budget : 20 A continu / 30 A crête 2 s (imposé par ESP32-SAFETY)           ║
║  ⚠️ La motorisation pourrait tirer 80 A — la batterie ne peut pas suivre.   ║
╚══════════════════════════════════════════════════════════════════════════════╝

  CHAÎNE D'ARRÊT, du plus rapide au plus autoritaire :
  N1 collision_monitor ~100ms │ N2 ros2_control ~50ms │ N3 ESP32-MOT 150ms
  N4 ESP32-SAFETY 20ms │ N5 CHAMPIGNON MATÉRIEL 10ms │ N6 coupe-batterie
  ★ Seul N5/N6 sont indépendants de tout logiciel ★
```

---

# V. Plan de réalisation par étapes

Chaque phase a un **critère de sortie mesurable**. On ne passe pas à la suivante sans l'avoir atteint.

## Phase 0 — Lever les incertitudes (avant tout achat de puissance)

**Durée 📐 : 1–2 semaines** · **Coût : ~200 €** (instrumentation)

| # | Tâche | Critère de sortie |
|---|---|---|
| V0.1 | Répondre aux **7 questions du §B.3** | Toutes documentées dans `docs/measurements/` |
| V0.2 | Acheter l'instrumentation de base : alimentation de labo à limitation de courant, multimètre, thermomètre IR | Disponible sur l'établi |
| V0.3 | **M12** — marquage des condensateurs des 4 ZS-X11H | ≥63 V confirmé, ou plan B décidé |
| V0.4 | **M5** — état du cavalier J1 | Documenté (n'affecte pas le choix DAC, mais informe) |
| V0.5 | **M9** — `lspci` sur le X1 : contrôleur USB 3.0 | Intel/NEC = OK Kinect · ASMedia = Kinect abandonné |
| V0.6 | **Installer Ubuntu 24.04 + ROS 2 Jazzy sur le X1** ⚠️ risque #33 | Boot, réseau, USB, UART, GPIO fonctionnels. Sinon : repli 22.04 + Humble, décision prise ici |
| V0.7 | **M2** — tension et résistance interne du pack | I_cc calculé → calibre de fusible confirmé |
| V0.8 | **M1** — ⚠️ seuil de coupure du BMS, sur banc protégé | Budget de courant recalé. **Si < 25 A → décision : 2 roues motrices ou changement de pack** |

⚠️ **V0.8 est le jalon le plus important du projet.** Tout le dimensionnement de puissance en dépend, et un résultat défavorable change l'architecture mécanique (4WD → 2WD) ou impose un nouveau pack. Mieux vaut le savoir maintenant.

## Phase 1 — Chaîne logicielle sans matériel

**Durée 📐 : 2–3 semaines** · **Coût : 0 €** · ⚠️ **Peut se faire en parallèle de la phase 0**

| # | Tâche | Critère de sortie |
|---|---|---|
| V1.1 | Créer le dépôt, l'arborescence, la CI | `colcon build` vert en CI |
| V1.2 | Écrire `protocol.yaml` + le générateur | `protocol.hpp` et `protocol.h` générés, tests unitaires passants |
| V1.3 | `retriever_msgs` | Compile |
| V1.4 | `retriever_description` : URDF, `physical_params.yaml` | `check_urdf` OK, TF complet dans RViz |
| V1.5 | `retriever_hardware` en mode mock puis loopback `vcan0` | Test d'intégration passant |
| V1.6 | `retriever_bringup` : lancement mock complet | Tous les nœuds actifs en < 20 s |
| V1.7 | Nav2 + EKF en simulation Gazebo | Le robot atteint un objectif à 10 m |
| V1.8 | Tests de niveau 5 automatisés | 100 % en CI |

**Critère de sortie de phase** : `ros2 launch retriever_bringup retriever.launch.py use_sim:=true` amène le robot simulé à naviguer vers un objectif. La totalité de la pile logicielle est validée **avant** qu'un seul fil de puissance ne soit serti.

## Phase 2 — Électronique basse tension

**Durée 📐 : 2–3 semaines** · **Coût : ~350 €**

| # | Tâche | Critère de sortie |
|---|---|---|
| V2.1 | Assembler les 3 ESP32 + transceivers CAN sur plaque d'essai | Bus CAN fonctionnel entre les 3, 0 erreur en 1 h |
| V2.2 | Adaptateur USB-CAN sur le X1 | `can0` UP, `candump` reçoit les trames des ESP32 |
| V2.3 | Firmware squelette : FSM, heartbeat, watchdogs | Tests de niveau 2 passants |
| V2.4 | BNO085 en SPI sur ESP32-SAFETY → CAN → `/imu/data` | 100 Hz, quaternion normé, test des 6 faces OK |
| V2.5 | MCP4728 + AOP : rampe 0–5 V vérifiée à l'oscilloscope | Linéaire, 0,00–5,00 V |
| V2.6 | ACS758 + ADS1115 : mesure sans courant | 2,50 V ± 0,05 |
| V2.7 | **M3** puis liaison BMS isolée | Registre 0x31 lu, SOC plausible |
| V2.8 | Ventilateurs PWM + tachy | Courbe thermique fonctionnelle |
| V2.9 | `retriever_can_bridge` : trames → topics ROS | `/imu/data`, `/battery_state`, `/retriever/safety_state` publiés |

**Critère de sortie** : le X1 voit l'IMU, la batterie et l'état de sécurité en ROS 2, sans aucun câble de puissance branché.

## Phase 3 — Chaîne de puissance, sans moteurs

**Durée 📐 : 2–3 semaines** · **Coût : ~600 €** · ⚠️ **Phase la plus dangereuse**

| # | Tâche | Critère de sortie |
|---|---|---|
| V3.1 | Fabriquer les busbars (perçage, étamage, capot) | Résistance de joint < 50 µΩ mesurée |
| V3.2 | Confectionner tous les câbles de puissance (sertissage hydraulique) | Tests de niveau 0 passants, test d'arrachement OK |
| V3.3 | Monter fusibles, sectionneur, contacteur, précharge | Câblage vérifié **deux fois**, par écrit |
| V3.4 | ⚠️ **Tests de niveau 1 à l'alimentation de laboratoire** (12 → 42 V, limitée en courant) | Tous les rails conformes, aucun courant anormal |
| V3.5 | Séquence de précharge + test de timeout sur court-circuit contrôlé | `FAULT_PRECHARGE` en < 1,5 s |
| V3.6 | ⚠️ **Première connexion du pack**, à 50 % de SoC, à l'extérieur, extincteur à portée | Courant au repos < 1,5 A |
| V3.7 | Chaîne d'arrêt d'urgence complète (champignon → `/SAFE` → contacteur RC) | Test actif : transition observée |
| V3.8 | Thermographie après 30 min | ΔT < 15 K entre jonctions identiques |
| V3.9 | Recouple à 48 h | Documenté |

**Critère de sortie** : le robot est sous tension, tous les rails sont bons, le champignon fonctionne, la thermographie est propre. **Aucun moteur n'est encore branché.**

## Phase 4 — Motorisation, roues levées

**Durée 📐 : 2–3 semaines** · **Coût : ~150 €**

| # | Tâche | Critère de sortie |
|---|---|---|
| V4.1 | **M4** — polarité `EL`/`STOP`, un moteur sur établi, alim de labo 24 V / 3 A | Documentée, temps d'arrêt mesuré |
| V4.2 | **M6, M7** — comptage Hall, niveau `SC` | 90 transitions/tour confirmées |
| V4.3 | Câblage Hall (74LVC245, RC, blindage) sur un moteur | PCNT compte dans le bon sens |
| V4.4 | Boucle PI de vitesse sur un moteur | Suivi < 10 %, réponse < 200 ms |
| V4.5 | Extension aux 4 moteurs, robot sur cales | Les 4 roues tournent, sens correct |
| V4.6 | Budget de courant + bridage progressif | Vérifié en chargeant artificiellement une roue |
| V4.7 | Tests de niveau 4 complets | Tous passants |
| V4.8 | Tests de niveau 6 (roues levées) : coupure du X1, du CAN, d'un ESP32, champignon | Arrêt < 500 ms dans tous les cas |

⚠️ **V4.8 est le jalon de sécurité.** Tant que ces tests ne passent pas, le robot ne touche pas le sol.

## Phase 5 — Premiers déplacements

**Durée 📐 : 1–2 semaines**

| # | Tâche | Critère de sortie |
|---|---|---|
| V5.1 | Roues au sol, **robot retenu par une sangle**, v ≤ 0,3 m/s, téléop | Comportement conforme |
| V5.2 | Libre, sol plat, v ≤ 0,5 m/s | Ligne droite sur 10 m, écart < 30 cm |
| V5.3 | Étalonnage `wheel_separation_multiplier` (rotation 360°) | ±5° |
| V5.4 | Odométrie sur carré de 5 m | Erreur de fermeture < 1 m |
| V5.5 | Test d'arrêt d'urgence **en mouvement au sol** | Distance d'arrêt mesurée et documentée |
| V5.6 | Mesure du courant de régénération en descente | < 15 A, sinon revoir la stratégie de freinage |

## Phase 6 — Navigation intérieure

**Durée 📐 : 2–3 semaines**

| # | Tâche | Critère de sortie |
|---|---|---|
| V6.1 | Intégrer le YDLIDAR X4 (build source, alim 5 V externe) | `/scan` à 7 Hz, > 60 % de points valides |
| V6.2 | Cohérence TF lidar/URDF | Erreur < 5 cm sur un mur connu |
| V6.3 | `slam_toolbox` en intérieur | Carte cohérente, boucle fermée |
| V6.4 | Nav2 intérieur | Objectif à 20 m atteint à ±30 cm |
| V6.5 | `collision_monitor` : obstacle sur la trajectoire | Arrêt avant contact |
| V6.6 | Mission de 30 min sans intervention | Journal propre |

## Phase 7 — Extérieur et GPS

**Durée 📐 : 3–4 semaines**

| # | Tâche | Critère de sortie |
|---|---|---|
| V7.1 | Intégrer le GPS, vérifier la covariance | ≥ 8 satellites, covariance non nulle |
| V7.2 | Monter le BNO085 sur mât, calibrer hard/soft iron | Cap stable moteurs en marche, ±10° |
| V7.3 | Comparer Rotation Vector (magnéto) vs Game RV (gyro) sur parcours en boucle | Le meilleur des deux retenu, documenté |
| V7.4 | Double EKF + `navsat_transform` | Trajectoire cohérente sur 100 m |
| V7.5 | Nav2 extérieur (MPPI, contraintes d'accélération) | Waypoints GPS atteints à ±3 m |
| V7.6 | Progression terrain : plat → irrégulier → pente 10 % | Aucun calage, courants journalisés |
| V7.7 | Mission complète 30 min en extérieur | Journal propre, autonomie mesurée |

## Phase 8 — Consolidation

**Durée 📐 : en continu**

| # | Tâche |
|---|---|
| V8.1 | Mettre à jour ce dossier avec toutes les valeurs mesurées (remplacer 🔴 et 📐 par ✅) |
| V8.2 | Documenter le plan de câblage réel, photos, étiquetage |
| V8.3 | Rédiger les procédures d'exploitation (mise en route, arrêt, maintenance) |
| V8.4 | Mettre en place le plan de maintenance (§R.7) |
| V8.5 | Évaluer les évolutions de phase 4 selon les limites rencontrées |

## V.1 Chemin critique et jalons

```
 Sem. 1-2   ████ Phase 0 — Incertitudes        ⚠️ M1 = jalon décisif
 Sem. 1-4   ████████ Phase 1 — Logiciel (en parallèle)
 Sem. 3-6   ████████ Phase 2 — Électronique BT
 Sem. 6-9   ████████ Phase 3 — Puissance       ⚠️ phase la plus dangereuse
 Sem. 9-12  ████████ Phase 4 — Moteurs levés   ⚠️ V4.8 = jalon sécurité
 Sem. 12-14 ████ Phase 5 — Premiers pas
 Sem. 14-17 ████████ Phase 6 — Nav intérieure
 Sem. 17-21 ██████████ Phase 7 — Extérieur + GPS
                                                → objectif « Nav2 autonome »
📐 ≈ 5 mois à raison de 8–12 h/semaine. Cohérent avec l'objectif de 3–6 mois.
```

**Trois jalons bloquants** :

| Jalon | Quoi | Si échec |
|---|---|---|
| **J1 — V0.8** | Seuil de coupure du BMS mesuré | Si < 25 A : passer en 2 roues motrices, ou changer de pack. **Décision d'architecture** |
| **J2 — V0.6** | Ubuntu 24.04 + ROS 2 Jazzy sur le X1 | Repli sur 22.04 + Humble, ou Docker. **Décision de plateforme** |
| **J3 — V4.8** | Tous les tests d'arrêt d'urgence passants, roues levées | **Interdiction de poser le robot au sol.** Non négociable |

## V.2 Ce qu'il faut faire en premier, cette semaine

Si tu ne fais qu'une chose :

1. **Répondre aux 7 questions du §B.3** — 20 minutes, et ça débloque tout le reste.
2. **`lspci -nn | grep -i usb` sur le X1** — 10 secondes, et ça décide du sort du Kinect.
3. **Regarder le marquage des condensateurs des 4 ZS-X11H** — 5 minutes, et ça évite peut-être 4 cartes détruites.
4. **Installer Ubuntu 24.04 + ROS 2 Jazzy sur le X1** — c'est le risque #33, et il est en tête du chemin critique.

Le reste peut attendre. Ces quatre points, non.

---

## Annexe — Sources

**Batterie et motorisation**
[Manuel Xiaomi Mi Electric Scooter](https://i01.appmifile.com/webfile/globalimg/Global_UG/Mi_Ecosystem/Mi_Electric_Scooter/en_V1.pdf) · [Manuel M365 Pro](https://i01.appmifile.com/webfile/globalimg/Global_UG/Mi_Ecosystem/Mi_Electric_Scooter_Pro/en-GB_V2.pdf) · [arXiv:2411.17184 — analyse matérielle du BMS M365](https://arxiv.org/html/2411.17184v1) · [BotoX/xiaomi-m365-compatible-bms](https://github.com/BotoX/xiaomi-m365-compatible-bms) · [CamiAlfa/M365-BLE-PROTOCOL](https://github.com/CamiAlfa/M365-BLE-PROTOCOL/blob/master/protocolo) · [ScooterHacking Wiki — ESC1](https://wiki.scooterhacking.org/doku.php?id=esc1-overview) · [MAD-EE — ZS-X11H](https://mad-ee.com/easy-inexpensive-hoverboard-motor-controller/) · [RoboFoundry — hoverboard motors](https://robofoundry.medium.com/cheaper-way-to-control-hoverboard-motors-79b02dd8a521) · [ODrive — docs/hoverboard.md](https://github.com/odriverobotics/ODrive/blob/master/docs/hoverboard.md)

**Capteurs et calculateur**
[YDLIDAR X4 Datasheet V2.0](https://download.kamami.pl/p1178202-YDLIDAR%20X4%20Data%20sheet%20V2.0.pdf) · [YDLIDAR X4 User Manual](https://static.generation-robots.com/media/ydlidar-x4-user-manual.pdf) · [BNO08X Datasheet Rev 1.17 (CEVA)](https://www.ceva-ip.com/wp-content/uploads/BNO080_085-Datasheet.pdf) · [Adafruit BNO085 guide](https://learn.adafruit.com/adafruit-9-dof-orientation-imu-fusion-breakout-bno085) · [ACS758 Datasheet Rev 20 (Allegro)](https://www.allegromicro.com/~/media/files/datasheets/acs758-datasheet.pdf) · [libfreenect2](https://github.com/OpenKinect/libfreenect2) · [libfreenect2 — Performance](https://github.com/OpenKinect/libfreenect2/wiki/Performance) · [krepa098/kinect2_ros2](https://github.com/krepa098/kinect2_ros2) · [Youyeetoo X1 wiki](https://wiki.youyeetoo.com/en/x1) · [CNX Software — X1 review part 2](https://www.cnx-software.com/2023/12/06/youyeetoo-x1-x86-sbc-review-gpio-uart-i2c-spi-nfc-poe-module-power-consumption/)

**ROS 2 Jazzy**
[REP-2000](https://www.ros.org/reps/rep-2000.html) · [ros2_control Jazzy — controllers](https://control.ros.org/jazzy/doc/ros2_controllers/doc/controllers_index.html) · [diff_drive_controller Jazzy](https://control.ros.org/jazzy/doc/ros2_controllers/diff_drive_controller/doc/userdoc.html) · [Guide de migration Jazzy](https://control.ros.org/jazzy/doc/ros2_controllers/doc/migration.html) · [Écrire un hardware component](https://control.ros.org/jazzy/doc/ros2_control/hardware_interface/doc/writing_new_hardware_component.html) · [Nav2 — Collision Monitor](https://docs.nav2.org/configuration/packages/collision_monitor/configuring-collision-monitor-node.html) · [Nav2 — MPPI](https://docs.nav2.org/configuration/packages/configuring-mppic.html) · [Nav2 — GPS Navigation](https://docs.nav2.org/tutorials/docs/navigation2_with_gps.html) · [robot_localization](https://index.ros.org/p/robot_localization/) · [slam_toolbox](https://index.ros.org/p/slam_toolbox/) · [Improved Dynamic Discovery (Jazzy)](https://docs.ros.org/en/jazzy/Tutorials/Advanced/Improved-Dynamic-Discovery.html) · [rmw_zenoh (jazzy)](https://github.com/ros2/rmw_zenoh/tree/jazzy) · [micro-ROS — hardware supporté](https://micro.ros.org/docs/overview/hardware/) · [micro_ros_platformio](https://github.com/micro-ROS/micro_ros_platformio) · [Vulcanexus — reconnexions micro-ROS](https://docs.vulcanexus.org/en/latest/rst/tutorials/micro/handle_reconnections/handle_reconnections.html) · [diagnostics](https://index.ros.org/r/diagnostics/) · [nav2_lifecycle_manager](https://docs.nav2.org/configuration/packages/configuring-lifecycle.html)

**Électricité DC, protections, busbars**
[Legrand F03693FR-01 — DX3 en courant continu](https://assets.legrand.com/pim/NP-FT-GT/F03693FR-01.pdf) · [Blue Sea 187-Series](https://www.bluesea.com/products/7146/) · [Blue Sea Class T 125 V / 20 kA](https://www.bluesea.com/products/5121/Class_T_Fuse_-_400_Amp) · [Victron — fusibles MIDI/MEGA/ANL 32, 58, 80 V](https://www.victronenergy.com/upload/documents/Datasheet-Midi,-Mega-and-ANL-fuses,-and-fuse-holders-EN-.pdf) · [Littelfuse ATO 32 V](https://www.mouser.com/datasheet/2/240/Littelfuse_BladeFuse_ATO32V-46883.pdf) · [Bussmann MRBF](https://www.currentconnected.com/product/cooper-bussmann-mrbf-terminal-fuse-30a-250a/) · [ABYC E-11 excerpts](https://www.paneltronics.com/images/technical/E11Excerpts.pdf) · [ISO 13297 — ampacité métrique](https://boathowto.com/wiresize/wiresize_tables_iso.pdf) · [ABYC E-11 Table 6A — groupement](https://boathowto.com/wiresize/wiresize_tables_abyc.pdf) · [Blue Sea — chute de tension](https://www.bluesea.com/support/articles/Circuit_Protection/1437/Part_1:_Choosing_the_Correct_Wire_Size_for_a_DC_Circuit) · [Copper Development Association — busbar ampacities](https://www.copper.org/applications/electrical/busbar/bus_table1.html) · [Storm Power — couple × revêtement sur la résistance de joint](https://stormpowercomponents.com/exploring-busbar-joint-resistance-a-study-on-the-effects-of-torque-and-plating/) · [MakerStage — Copper Bus Bar Design Guide](https://www.makerstage.com/resources/copper-electrical-contacts-design) · [Sensata — conception des circuits de précharge](https://www.sensata.com/sites/default/files/a/sensata-how-to-design-precharge-circuits-evs-whitepaper.pdf) · [TI SLVAE57 — Basics of Ideal Diodes](https://www.ti.com/lit/an/slvae57b/slvae57b.pdf) · [TI SLUP419 — Clearance and Creepage (IEC 60664-1)](https://www.ti.com/lit/pdf/slup419) · [CED Engineering — Arc Flash en DC](https://www.cedengineering.com/userfiles/Arc%20Flash%20Hazard%20Calculations%20in%20DC%20Systems%20R1.pdf) · [Enatel — essais de court-circuit Li-ion](https://www.enatel.net/wp-content/uploads/2024/08/Short-Circuit-Testing-of-Li-ion-in-standby-applications-Murray-Wyma.pdf) · [Leroy Merlin — profilés laiton (aucune barre cuivre)](https://www.leroymerlin.fr/produits/quincaillerie/corniere-tube-tole-et-profile/corniere-et-profile/profile-laiton/) · [Leroy Merlin — coffret IP65 rail DIN](https://www.leroymerlin.fr/produits/coffret-etanche-avec-rail-din-pour-5-modules-ip65-87615283.html)

---

*Fin du dossier d'architecture — version 1.0, 8 août 2026.*
*Ce document est vivant : chaque mesure réalisée doit y remplacer un 🔴 ou un 📐 par un ✅.*

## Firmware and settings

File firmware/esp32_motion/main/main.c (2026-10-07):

/* Retriever MOTION bench, common front/rear/four-wheel image source. Apache-2.0. */
#include <inttypes.h>
#include <string.h>
#include "esp_err.h"
#include "esp_log.h"
#include "esp_timer.h"
#include "freertos/FreeRTOS.h"
#include "freertos/task.h"
#include "board_config.h"
#include "motors.h"
#include "retriever_link/link.h"
#include "retriever_link/link_log.h"

static const char *TAG = "motion";
static uint8_t s_app_passed, s_app_failed;

static bool on_frame(const rt_frame_t *f, void *user)
{
    (void)user;
    switch (f->id) {
    case RT_ID_MOTOR_CMD: {
        rt_motor_cmd_t c;
        if (!rt_motor_cmd_unpack(f, &c)) { rt_motors_reject(); return true; }
        const float duty[4] = {c.m0, c.m1, c.m2, c.m3};
        (void)rt_motors_command(duty);
        return true;
    }
    case RT_ID_MOTOR_ENABLE: {
        rt_motor_enable_t e;
        if (!rt_motor_enable_unpack(f, &e) || e.magic != 0xEBu) {
            rt_motors_reject(); return true;
        }
        (void)rt_motors_enable(e.enable_mask);
        return true;
    }
    case RT_ID_MOTOR_SESSION: {
        rt_motor_session_t s;
        if (!rt_motor_session_unpack(f, &s) || s.magic != 0xB2u) {
            rt_motors_reject(); return true;
        }
        if (s.target == BOARD_NODE_ID) (void)rt_motors_session(s.protocol_hash);
        return true;
    }
    case RT_ID_ESTOP_REQUEST: {
        rt_estop_request_t e;
        if (rt_estop_request_unpack(f, &e) && e.magic == 0xE5u) rt_motors_estop();
        else rt_motors_reject();
        return true;
    }
    case RT_ID_LINK_PING: {
        rt_link_ping_t p;
        if (!rt_link_ping_unpack(f, &p) || p.target != BOARD_NODE_ID) return true;
        const rt_link_pong_t pong = {.source = BOARD_NODE_ID, .seq = p.seq, .t_tx_us = p.t_tx_us};
        rt_frame_t out;
        rt_link_pong_pack(&pong, &out);
        rt_link_send_urgent(&out);
        return true;
    }
    default: return false;
    }
}

static uint16_t sat16(uint32_t v) { return v > 65535 ? 65535 : (uint16_t)v; }

static void housekeeping_task(void *arg)
{
    (void)arg;
    /* Publishing READY before installing the RX hook lets the host send its
     * session to a receiver that still drops commands during startup. */
    ulTaskNotifyTake(pdTRUE, portMAX_DELAY);
    TickType_t wake = xTaskGetTickCount();
    unsigned ticks = 0;
    for (;;) {
        rt_frame_t f;
        /* Bound draining so traffic from other nodes cannot starve diagnostics. */
        for (int i = 0; i < 32 && rt_link_recv(&f, 0) == ESP_OK; ++i) {}
        rt_link_stats_t st;
        rt_link_get_stats(&st);
        if (st.bus_off) rt_motors_estop(); /* Recovery never re-arms outputs. */
        rt_motors_state_t m;
        rt_motors_get_state(&m);
        rt_motor_state_t state = {
            .applied_m0 = m.applied[0], .applied_m1 = m.applied[1],
            .applied_m2 = m.applied[2], .applied_m3 = m.applied[3],
            .enable_mask = m.enable_mask, .flags = m.flags, .cmd_age_ms = sat16(m.cmd_age_ms),
        };
        rt_motor_state_pack(&state, &f);
#if CONFIG_RETRIEVER_ROLE_REAR
        f.id = RT_ID_MOTOR_STATE_REAR; /* Identical layout, distinct CAN arbitration ID. */
#endif
        rt_link_send(&f, 0);
        const rt_motor_diag_front_t diag = {
            .passed = m.selftest_passed | s_app_passed,
            .failed = m.selftest_failed | s_app_failed,
            .configured_mask = m.configured_mask, .flags = m.flags,
            .rejected = sat16(m.rejected), .output_errors = sat16(m.output_errors),
        };
        rt_motor_diag_front_pack(&diag, &f);
#if CONFIG_RETRIEVER_ROLE_REAR
        f.id = RT_ID_MOTOR_DIAG_REAR;
#endif
        rt_link_send(&f, 0);
        const uint64_t errors = (uint64_t)st.framing.crc_errors + st.framing.format_errors +
            st.framing.overflows + st.rx_dropped + st.tx_dropped + st.bus_errors +
            m.rejected + m.output_errors;
        const bool fault = diag.failed || (m.flags & RT_MOTOR_FLAG_OUTPUT_FAULT);
        const bool degraded = st.bus_off || (m.flags & RT_MOTOR_FLAG_ESTOP) ||
            ((m.flags & RT_MOTOR_FLAG_CMD_TIMEOUT) && !(m.flags & RT_MOTOR_FLAG_NEVER_ARMED));
        const rt_heartbeat_motion_front_t hb = {
            .state = fault ? RT_NODE_STATE_FAULT : (degraded ? RT_NODE_STATE_DEGRADED :
                ((m.flags & RT_MOTOR_FLAG_ENABLED) ? RT_NODE_STATE_ACTIVE : RT_NODE_STATE_READY)),
            .uptime_s = (uint16_t)(esp_timer_get_time() / 1000000),
            .err_count = errors > 255 ? 255 : (uint8_t)errors, .protocol_hash = RT_PROTOCOL_HASH,
        };
        rt_heartbeat_motion_front_pack(&hb, &f);
#if CONFIG_RETRIEVER_ROLE_REAR
        f.id = RT_ID_HEARTBEAT_MOTION_REAR;
#endif
        rt_link_send(&f, 0);
        if (++ticks % 10 == 0) {
            ESP_LOGI(TAG, "%s roues=0x%02x selftest=%02x/%02x masque=%02x flags=%02x age=%" PRIu32
                     "ms rejetees=%" PRIu32 " erreurs-sortie=%" PRIu32,
                     BOARD_ROLE_NAME, m.configured_mask, diag.passed, diag.failed,
                     m.enable_mask, m.flags, m.cmd_age_ms, m.rejected, m.output_errors);
            ESP_LOGI(TAG, "readback pwm=[%u,%u,%u,%u] stop_gpio_high=0x%02x",
                     m.pwm_readback[0], m.pwm_readback[1], m.pwm_readback[2], m.pwm_readback[3],
                     m.stop_gpio_high);
        }
        vTaskDelayUntil(&wake, pdMS_TO_TICKS(100));
    }
}

void app_main(void)
{
    const rt_motor_pins_t pins[4] = BOARD_MOTOR_TABLE;
    rt_motors_config_t cfg = {
        .count = CONFIG_RETRIEVER_MOTOR_COUNT, .first_motor = BOARD_FIRST_MOTOR,
        .pwm_freq_hz = BOARD_PWM_FREQ_HZ, .pwm_resolution_bits = BOARD_PWM_RESOLUTION_BITS,
#if CONFIG_RETRIEVER_MOTOR_LOGIC_INVERTED
        .logic_inverted = true,
#endif
        .cmd_timeout_ms = CONFIG_RETRIEVER_MOTOR_CMD_TIMEOUT_MS,
        .reverse_deadtime_ms = CONFIG_RETRIEVER_MOTOR_REVERSE_DEADTIME_MS,
        .slew_per_s = CONFIG_RETRIEVER_MOTOR_SLEW_PER_S / 1000.0f,
        .duty_limit = CONFIG_RETRIEVER_MOTOR_DUTY_LIMIT_MILLI / 1000.0f,
    };
    memcpy(cfg.pins, pins, sizeof(pins));
    const esp_err_t motor_err = rt_motors_init(&cfg); /* Zero outputs before communications. */
    rt_link_config_t link = RT_LINK_CONFIG_BENCH_DEFAULT();
    link.node_id = BOARD_NODE_ID;
#if CONFIG_RETRIEVER_LINK_BACKEND_TWAI
    link.backend = RT_LINK_BACKEND_TWAI;
#endif
    const esp_err_t link_err = rt_link_init(&link);
    if (link_err != ESP_OK) {
        rt_motors_estop();
        ESP_LOGE(TAG, "liaison: %s; aucun armement possible", esp_err_to_name(link_err));
        return;
    }
    s_app_passed |= RT_MOTOR_SELFTEST_LINK;
#if CONFIG_RETRIEVER_LINK_CONSOLE_TUNNEL && !CONFIG_RETRIEVER_LINK_BACKEND_TWAI
    rt_link_log_install(); /* Shared LOG ID is only appropriate on a point-to-point bench. */
#endif
    ESP_LOGI(TAG, "motion %s: protocole %s 0x%08" PRIX32 "; init=%s",
             BOARD_ROLE_NAME, RT_PROTOCOL_VERSION, (uint32_t)RT_PROTOCOL_HASH, esp_err_to_name(motor_err));
    /* Start diagnostics even if the motor self-test failed. Never accept enable
     * until both output and housekeeping tasks have been created. */
    TaskHandle_t house_task = NULL;
    if (xTaskCreate(housekeeping_task, "house", 4096, NULL, 5, &house_task) != pdPASS) {
        s_app_failed |= RT_MOTOR_SELFTEST_TASK;
        rt_motors_estop();
        ESP_LOGE(TAG, "tache diagnostic absente: armement interdit");
        return;
    }
    if (motor_err == ESP_OK) rt_link_set_rx_hook(on_frame, NULL);
    xTaskNotifyGive(house_task);
}

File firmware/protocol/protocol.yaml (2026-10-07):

# =============================================================================
#  protocol.yaml — Retriever · source unique de vérité du protocole de liaison
# =============================================================================
#  Ce fichier décrit TOUTES les trames échangées entre le calculateur et les
#  microcontrôleurs. Il génère, par `generate.py` :
#
#    firmware/protocol/generated/retriever_protocol.h                   (C99)
#    ros2_ws/src/retriever_protocol/include/retriever_protocol/          (C++17)
#      protocol.hpp
#    docs/architecture/generated/protocol-tables.md                      (doc)
#
#  RÈGLE : on ne recopie JAMAIS une constante de ce fichier à la main dans du
#  code. Toute constante utilisée par le firmware ou par ROS 2 vient de
#  l'en-tête généré. `tools/check_protocol_sync.py` échoue en CI si les fichiers
#  générés ne correspondent plus à ce YAML.
#
#  Le champ meta.hash est calculé par le générateur sur le contenu normalisé du
#  fichier. Il est compilé dans le firmware et remonté dans chaque HEARTBEAT :
#  une divergence entre un nœud et le calculateur est un refus d'armement, pas
#  un avertissement (§K.2 [P3]).
#
#  Version : 0.2.0 — 4 octobre 2026
#  Référence : dossier d'architecture §F.3 (plan d'adressage), §AB (couche de
#  liaison). Les écarts par rapport au §F.3 sont listés dans §AB.7.
# =============================================================================

meta:
  version: "0.2.0"
  date: "2026-10-04"
  endianness: little          # Intel. Aucun échange d'octets sur ESP32 ni x86.
  id_bits: 11                 # CAN 2.0A. Conservé tel quel sur le transport série.
  max_payload: 8              # Contrainte CAN. Volontairement conservée en série.

  transports:
    can:
      bitrate: 500000
      standard: "CAN 2.0A, 11 bits, ISO 11898-2"
      status: target          # cible, non câblée : la carte CAN n'est pas conçue
    serial:
      framing: cobs           # délimiteur 0x00, voir §AC
      crc: crc16_ccitt_false  # polynôme 0x1021, init 0xFFFF, pas de réflexion
      default_baud: 921600
      status: bench           # transport de développement UNIQUEMENT (§AB.5)

# -----------------------------------------------------------------------------
#  Énumérations
# -----------------------------------------------------------------------------
enums:

  node_id:
    doc: "Identité d'un nœud. Sert d'index dans HEARTBEAT (0x700 + node_id)."
    values:
      HOST:    0    # le calculateur lui-même (X1)
      SAFETY:  1
      MOTION_FRONT: 2
      MOTION_REAR:  3

  imu_cal_action:
    doc: >
      Commandes d'étalonnage de l'IMU, portées par IMU_CAL_CMD. Le BNO085 sait
      corriger ses biais en fonctionnement, mais il faut le lui demander, et
      l'écrire en flash pour que ça survive à la mise hors tension.
    values:
      NONE:    0
      ENABLE:  1   # active l'étalonnage dynamique sur les capteurs du masque
      DISABLE: 2   # fige les corrections en cours
      SAVE:    3   # écrit le DCD en flash, sans reset
      CLEAR:   4   # efface le DCD et redémarre le capteur — dernier recours

  node_state:
    doc: "État de haut niveau publié par tout nœud dans son HEARTBEAT."
    values:
      BOOT:      0   # avant self_test
      SELFTEST:  1
      READY:     2   # opérationnel, pas d'autorisation de mouvement
      ACTIVE:    3   # autorisé à agir
      DEGRADED:  4
      FAULT:     5

  safety_state:
    doc: "FSM de sécurité de l'ESP32-SAFETY (§J.2). Autoritaire."
    values:
      INIT:          0
      SAFE:          1
      PRECHARGE:     2
      LIVE_DISARMED: 3
      LIVE_ARMED:    4
      BRAKING:       5
      FAULT:         6
      ESTOP:         7

  fault_cause:
    doc: >
      Cause du dernier passage en BRAKING / FAULT / ESTOP. Mémorisée et publiée
      tant que le défaut n'est pas acquitté : un robot qui s'arrête doit dire
      pourquoi (§J.2).
    values:
      NONE:              0
      ESTOP_BUTTON:      1
      HOST_HEARTBEAT:    2
      NODE_HEARTBEAT:    3
      BUS_OFF:           4
      OVERCURRENT:       5
      OVERCURRENT_SLOW:  6
      UNDERVOLTAGE:      7
      OVERVOLTAGE_REGEN: 8
      OVERTEMP:          9
      TILT:             10
      PRECHARGE_TIMEOUT: 11
      CONTACTOR_STUCK:  12
      WATCHDOG:         13
      PROTOCOL_MISMATCH: 14
      SELFTEST_FAILED:  15

  wheel_flag:
    doc: "Drapeaux par roue (§H.5). Champ de bits."
    bitfield: true
    values:
      STALL:       0x01
      HALL_FAULT:  0x02
      CMD_TIMEOUT: 0x04
      DRIVER_FAULT: 0x08
      CURRENT_LIMIT: 0x10
      OVERTEMP:    0x20
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

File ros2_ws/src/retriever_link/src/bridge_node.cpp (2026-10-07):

// Copyright 2026 William Hanczyk — Apache License 2.0
// ===========================================================================
//  bridge_node.cpp — le pont entre la liaison et le graphe ROS 2
//
//  Un seul nœud, deux responsabilités qui ne doivent pas se mélanger :
//
//    1. lire des trames et en faire des messages ROS PROPRES — unités SI,
//       repères REP-103, covariances renseignées, horodatage cohérent ;
//    2. dire si la liaison va bien, et le dire assez fort pour qu'on le voie
//       avant que ça n'ait des conséquences.
//
//  Ce que ce nœud ne fait PAS, volontairement : il ne filtre pas, ne fusionne
//  pas, ne corrige pas. Un pont qui « améliore » les données est un pont dans
//  lequel on ne peut plus avoir confiance quand quelque chose cloche. Le
//  filtrage est le travail de robot_localization, en aval, et il est fait une
//  fois pour toutes les sources.
//
//  Copyright (c) 2026 William Hanczyk — Apache License 2.0
// ===========================================================================

#include <algorithm>
#include <array>
#include <atomic>
#include <cctype>
#include <chrono>
#include <cmath>
#include <memory>
#include <mutex>
#include <stdexcept>
#include <string>
#include <thread>

#include "diagnostic_msgs/msg/diagnostic_status.hpp"
#include "diagnostic_updater/diagnostic_status_wrapper.hpp"
#include "diagnostic_updater/diagnostic_updater.hpp"
#include "geometry_msgs/msg/transform_stamped.hpp"
#include "rclcpp/rclcpp.hpp"
#include "sensor_msgs/msg/imu.hpp"
#include "sensor_msgs/msg/magnetic_field.hpp"
#include "tf2_ros/transform_broadcaster.hpp"
#include "visualization_msgs/msg/marker.hpp"

#include "retriever_link/imu_conversion.hpp"
#include "retriever_link/serial_transport.hpp"
#include "retriever_link/socketcan_transport.hpp"
#include "retriever_msgs/msg/imu_status.hpp"
#include "retriever_msgs/msg/link_status.hpp"
#include "retriever_msgs/msg/motor_command.hpp"
#include "retriever_msgs/msg/motor_enable.hpp"
#include "retriever_msgs/msg/motor_state.hpp"
#include "retriever_msgs/msg/motor_diagnostics.hpp"
#include "retriever_msgs/msg/node_status.hpp"
#include "std_msgs/msg/empty.hpp"

namespace retriever::link
{

using namespace std::chrono_literals;

class BridgeNode : public rclcpp::Node
{
public:
  BridgeNode()
  : rclcpp::Node("retriever_link_bridge"), diagnostics_(this)
  {
    declare_parameters();
    build_transport();
    build_publishers();
    build_diagnostics();

    running_ = true;
    reader_ = std::thread(&BridgeNode::reader_loop, this);

    if (time_sync_enabled_) {
      time_sync_timer_ = create_wall_timer(1s, [this] {send_time_sync();});
    }
    if (ping_period_s_ > 0.0) {
      ping_timer_ = create_wall_timer(
        std::chrono::duration<double>(ping_period_s_), [this] {send_ping();});
    }
    status_timer_ = create_wall_timer(500ms, [this] {publish_status();});

    if (motors_enabled_) {
      build_motor_side();
    }

    RCLCPP_INFO(
      get_logger(), "pont pret sur %s, protocole %s (0x%08X)",
      transport_->describe().c_str(), std::string(protocol::kVersion).c_str(),
      protocol::kHash);
  }

  ~BridgeNode() override
  {
    running_ = false;
    if (reader_.joinable()) {
      reader_.join();
    }
    if (transport_) {
      transport_->close();
    }
  }

private:
  // -----------------------------------------------------------------------
  //  Paramètres
  // -----------------------------------------------------------------------
  void declare_parameters()
  {
    transport_kind_ = declare_parameter<std::string>("transport", "serial");
    serial_device_ = declare_parameter<std::string>("serial.device", "/dev/ttyUSB0");
    serial_baud_ = declare_parameter<int>("serial.baudrate", 921600);
    // Voir SerialTransport : sur une DevKitC, ouvrir le port peut faire
    // démarrer la carte en mode téléchargement, où elle est muette. Le nœud la
    // remet donc en mode exécution à l'ouverture. À passer à false sur un
    // montage où redémarrer le microcontrôleur au démarrage du nœud n'est pas
    // acceptable — sur CAN, la question ne se pose pas.
    serial_reset_on_open_ = declare_parameter<bool>("serial.reset_on_open", true);
    can_interface_ = declare_parameter<std::string>("can.interface", "can0");

    frame_id_ = declare_parameter<std::string>("frame_id", "imu_link");

    // ⚠️ Le protocole ne transporte pas d'horodatage : les huit octets d'une
    // trame sont pleins. On date donc à la réception, moins une latence
    // constante. Cette constante N'EST PAS une devinette : elle se mesure, avec
    // LINK_PING, et la recette B1 dit comment. La valeur par défaut est un
    // ordre de grandeur 📐 tant que la mesure n'est pas faite.
    latency_offset_ms_ = declare_parameter<double>("link.latency_offset_ms", 1.5);
    ping_period_s_ = declare_parameter<double>("link.ping_period_s", 1.0);
    time_sync_enabled_ = declare_parameter<bool>("link.time_sync", true);
    // Quel microcontrôleur est au bout de CE lien. Un pont par liaison série :
    // le banc IMU parle au nœud SAFETY, le banc moteurs au nœud MOTION_FRONT.
    // Ça fixe la cible des pings, le nom du diagnostic et l'identifiant
    // matériel — pas le décodage, qui accepte toutes les trames connues.
    peer_ = declare_parameter<std::string>("link.peer", "safety");
    if (peer_ == "safety") {
      peer_node_id_ = RT_NODE_ID_SAFETY;
    } else if (peer_ == "motion_front") {
      peer_node_id_ = RT_NODE_ID_MOTION_FRONT;
    } else if (peer_ == "motion_rear") {
      peer_node_id_ = RT_NODE_ID_MOTION_REAR;
    } else {
      throw std::runtime_error("link.peer doit valoir 'safety', 'motion_front' ou 'motion_rear'");
    }
    imu_enabled_ = declare_parameter<bool>("imu.enabled", peer_ == "safety");

    // Banc moteurs (§Z). Désactivé par défaut : un pont IMU ne doit pas pouvoir
    // émettre une MOTOR_CMD, même par erreur de câblage.
    motors_enabled_ = declare_parameter<bool>(
      "motors.enabled", peer_ == "motion_front" || peer_ == "motion_rear");
    motors_rate_hz_ = declare_parameter<double>("motors.rate_hz", 50.0);
    motors_cmd_timeout_s_ = declare_parameter<double>("motors.command_timeout_s", 0.5);
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

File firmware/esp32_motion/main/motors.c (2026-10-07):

/* One task owns GPIO/LEDC. The portable policy is shared with host tests. Apache-2.0. */
#include "motors.h"
#include <inttypes.h>
#include <math.h>
#include <string.h>
#include "driver/gpio.h"
#include "driver/ledc.h"
#include "esp_log.h"
#include "esp_timer.h"
#include "esp_task_wdt.h"
#include "freertos/FreeRTOS.h"
#include "freertos/task.h"

static const char *TAG = "motors";
static portMUX_TYPE s_lock = portMUX_INITIALIZER_UNLOCKED;
static rt_motors_config_t s_cfg;
static rt_motor_control_t s_control;
static uint8_t s_passed, s_failed;
static uint32_t s_output_errors;
static bool s_initialized;
static int s_pwm_channels;
/* Last writes and next-cycle peripheral readback. Only ctrl_task writes these. */
static float s_written[4], s_confirmed[4];
static uint16_t s_pwm_readback[4];
static uint8_t s_stop_levels;

static uint32_t duty_ticks(float duty)
{
    return (uint32_t)lroundf(fabsf(duty) * (float)((1u << s_cfg.pwm_resolution_bits) - 1u));
}

static esp_err_t logic_set(int pin, int driver_level)
{
    return gpio_set_level((gpio_num_t)pin, s_cfg.logic_inverted ? !driver_level : driver_level);
}

static esp_err_t output_set(int slot, float duty)
{
    const rt_motor_pins_t *p = &s_cfg.pins[slot];
    const bool run = duty != 0;
    esp_err_t err;
    if (!run && (err = logic_set(p->stop, 0)) != ESP_OK) return err;
    /* Keep DIR unchanged at zero, including throughout reversal dead time. */
    if (run && (err = logic_set(p->dir, duty > 0)) != ESP_OK) return err;
    err = ledc_set_duty(LEDC_LOW_SPEED_MODE, (ledc_channel_t)slot,
                        duty_ticks(duty));
    if (err != ESP_OK) return err;
    err = ledc_update_duty(LEDC_LOW_SPEED_MODE, (ledc_channel_t)slot);
    if (err != ESP_OK) return err;
    return run ? logic_set(p->stop, 1) : ESP_OK;
}

/* Best effort even after a peripheral failure. STOP first on every slot. */
static void outputs_safe(void)
{
    for (int i = 0; i < s_cfg.count; ++i) (void)logic_set(s_cfg.pins[i].stop, 0);
    for (int i = 0; i < s_pwm_channels; ++i) {
        (void)ledc_set_duty(LEDC_LOW_SPEED_MODE, (ledc_channel_t)i, 0);
        (void)ledc_update_duty(LEDC_LOW_SPEED_MODE, (ledc_channel_t)i);
    }
    memset(s_written, 0, sizeof(s_written));
}

static esp_err_t fail(uint8_t test, esp_err_t err)
{
    outputs_safe();
    portENTER_CRITICAL(&s_lock);
    s_failed |= test;
    s_output_errors++;
    rt_motor_control_stop(&s_control, true);
    rt_motor_control_step(&s_control, esp_timer_get_time());
    portEXIT_CRITICAL(&s_lock);
    ESP_LOGE(TAG, "self-test 0x%02x: %s; sorties interdites", test, esp_err_to_name(err));
    return err;
}

static void ctrl_cycle(void)
{
    /* Read AFTER the previous PWM update has had a full control period to
     * reach the hardware. A successful API call alone is not output feedback.
     * This measures peripheral registers and STOP pads, not wheel rotation. */
    uint16_t raw[4] = {0};
    float confirmed[4] = {0};
    uint8_t stop_levels = 0, bad = 0;
    for (int slot = 0; slot < s_cfg.count; ++slot) {
        const int global = s_cfg.first_motor + slot;
        raw[global] = ledc_get_duty(LEDC_LOW_SPEED_MODE, (ledc_channel_t)slot);
        const int stop = gpio_get_level((gpio_num_t)s_cfg.pins[slot].stop);
        const int expected_stop = s_cfg.logic_inverted ? s_written[global] == 0 : s_written[global] != 0;
        stop_levels |= (uint8_t)(stop << global);
        confirmed[global] = copysignf((float)raw[global] /
            (float)((1u << s_cfg.pwm_resolution_bits) - 1u), s_written[global]);
        if (raw[global] != duty_ticks(s_written[global])) bad |= RT_MOTOR_SELFTEST_PWM;
        if (stop != expected_stop) bad |= RT_MOTOR_SELFTEST_GPIO;
        if (raw[global] != duty_ticks(s_written[global]) || stop != expected_stop)
            ESP_LOGE(TAG, "readback m%d pwm=%u/%" PRIu32 " stop=%d/%d", global,
                     raw[global], duty_ticks(s_written[global]), stop, expected_stop);
    }
    portENTER_CRITICAL(&s_lock);
    memcpy(s_confirmed, confirmed, sizeof(confirmed));
    memcpy(s_pwm_readback, raw, sizeof(raw));
    s_stop_levels = stop_levels;
    portEXIT_CRITICAL(&s_lock);
    if (bad) { (void)fail(bad, ESP_FAIL); return; }

    float applied[4];
    portENTER_CRITICAL(&s_lock);
    rt_motor_control_step(&s_control, esp_timer_get_time());
    memcpy(applied, s_control.applied, sizeof(applied));
    portEXIT_CRITICAL(&s_lock);
    /* Inhibit every inactive output first, including ones that were already
     * zero. Only then update active outputs. All writes share this one owner. */
    for (int phase = 0; phase < 2; ++phase) {
        for (int slot = 0; slot < s_cfg.count; ++slot) {
            const int global = s_cfg.first_motor + slot;
            if ((applied[global] != 0) != (phase != 0)) continue;
            const esp_err_t err = output_set(slot, applied[global]);
            if (err != ESP_OK) { (void)fail(RT_MOTOR_SELFTEST_PWM, err); return; }
            s_written[global] = applied[global];
        }
    }
}

static void ctrl_task(void *arg)
{
    (void)arg;
    if (esp_task_wdt_add(NULL) != ESP_OK) {
        (void)fail(RT_MOTOR_SELFTEST_TASK, ESP_FAIL);
        vTaskDelete(NULL);
        return;
    }
    portENTER_CRITICAL(&s_lock);
    s_passed |= RT_MOTOR_SELFTEST_TASK;
    portEXIT_CRITICAL(&s_lock);
    TickType_t wake = xTaskGetTickCount();
    for (;;) {
        vTaskDelayUntil(&wake, pdMS_TO_TICKS(5));
        if (esp_task_wdt_reset() != ESP_OK) {
            (void)fail(RT_MOTOR_SELFTEST_TASK, ESP_FAIL);
            vTaskDelete(NULL);
            return;
        }
        ctrl_cycle();
    }
}

static bool pins_valid(const rt_motors_config_t *cfg)
{
    uint64_t used = (1ULL << 1) | (1ULL << 3) | (1ULL << 4) | (1ULL << 5);
    for (int i = 0; i < cfg->count; ++i) {
        const int pins[] = {cfg->pins[i].pwm, cfg->pins[i].dir, cfg->pins[i].stop};
        for (int k = 0; k < 3; ++k) {
            const int p = pins[k];
            if (!GPIO_IS_VALID_OUTPUT_GPIO(p) || p < 0 || p > 33 ||
                p == 0 || p == 2 || (p >= 6 && p <= 12) ||
                p == 15 || p == 16 || p == 17 || (used & (1ULL << p))) return false;
            used |= 1ULL << p;
        }
    }
    return true;
}
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

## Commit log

2026-08-23 Initial commit: project structure, architecture dossier, licences
    Retriever is a four wheel drive outdoor mobile robot running ROS 2 Jazzy.
    This commit lays down the repository structure and publishes the eight
    document architecture dossier written before construction began.
    Code under Apache 2.0, hardware under CERN OHL S v2.
2026-08-23 docs: add CAD renders, deck files and the two PCB specifications
    Renders
    - 17 views of the current assembly, captured from the Fusion 360 viewport
    by script: two hero shots, two angled shots, four orthographic views for
    dimensioning, three internal views and three details
    - all 1600 x 900 and quantised, 2.5 MB total, per the docs/images policy
    - hero image wired into the README, plus a four image design section
    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
    [deck-bracket-rear.stl, deck-bracket-standard.stl, upper-deck-550x276.dxf]
2026-08-24 Update CAD and sponsorship READMEs, restore BOM document, add build photos
    [ETG_Plateau_superieur_PMMA_3mm.dxf, Panneau_ARRIERE.dxf, Panneau_AVANT.dxf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]
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2026-09-11 Couche de liaison agnostique du transport, et premier capteur jusqu'à ROS 2
    Le dossier tranche que le bus temps réel est un bus CAN. La carte de
    distribution n'existe pas, et le logiciel n'a pas à l'attendre : on sépare
    le protocole de son transport et on développe en série en écrivant le code
    comme si c'était déjà du CAN.
    Protocole
    protocol.yaml devient la source unique. Le générateur produit l'en-tête C
    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
2026-09-11 Corrections issues de la relecture croisée du firmware et de la pile ROS
    Deux bloquants de compilation, un défaut SPI qui aurait bloqué la chaîne IMU
    en silence, et une série de points où le code et le commentaire disaient
    deux choses différentes.
    Bloquants
    board_config.h : SPI3_HOST n'était déclaré nulle part.
    main.c : CONFIG_RETRIEVER_IMU_ENABLE_MAG utilisé dans une expression C —
    Kconfig ne définit un booléen que lorsqu'il vaut y, donc l'option à n
    cassait la compilation.
    retriever_protocol : rt_framing.h inclut "retriever_protocol.h" sans
    préfixe, ce que le chemin d'inclusion du paquet ROS ne fournissait pas.
    retriever_link : ament_target_dependencies sans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
    [board_config.h, bridge_node.cpp, imu.h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]
2026-09-11 Le script de dépendances vérifie son propre résultat
    git submodule update --init ne fait rien, et ne dit rien, quand le lien vers
    le sous-module a disparu de l'index. L'erreur ne se manifeste qu'au premier
    idf.py build, plusieurs minutes plus tard et plusieurs couches plus bas.
    Le script tente le sous-module, vérifie que sh2.c est bien là, se replie sur
    un clonage direct au tag épinglé sinon, et refuse de rendre la main sans
    avoir vérifié. Il signale aussi le cas où la compilation marchera localement
    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
2026-09-11 Inclusion explicite de esp_attr.h pour IRAM_ATTR et WORD_ALIGNED_ATTR
    Les deux arrivaient par transitivité depuis driver/gpio.h. Une dépendance
    d'inclusion qu'on n'a pas écrite est une dépendance qu'une mise à jour d'IDF
    peut retirer.
    Claude-Session: https://claude.ai/code/session_019iSUBG2bteBnbqvcotEM9D
2026-09-11 Câblage du BNO085 : la broche d'adresse I2C devient MOSI en SPI
    Le commentaire de board_config.h associait SDA à MOSI. C'est l'inverse : la
    datasheet BNO08x donne la broche 20 (H_SDA en I2C) comme H_MISO, et la broche
    17 (SA0, la sélection d'adresse I2C) comme H_MOSI. Selon les cartes, cette
    dernière est sérigraphiée ADDR, ADR, SA0, DI ou SI.
    L'erreur ne produit rien d'observable : le capteur ne répond simplement
    jamais, et on cherche du côté du mode SPI ou de la séquence PS0/PS1.
    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
    [board_config.h]
2026-09-11 Latence d'émission, et journaux du firmware enfin visibles
    Deux défauts révélés par le premier banc réel.
    La file urgente ne servait à rien. La tâche d'émission bloquait 20 ms sur la
    file normale, donc une trame urgente déposée juste après le début de cette
    attente y restait jusqu'à son expiration. Mesuré sur le banc : 52 ms
    d'aller-retour au lieu de quelques millisecondes — 20 ms d'émission, 20 ms de
    réception, le reste côté hôte. Ces 26 ms se seraient retrouvés, par
    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
2026-09-11 Instrumenter le chemin SPI, et corriger la mesure d'aller-retour
    Le capteur répond à son identification mais n'émet aucun rapport. Le journal
    dit « ecriture refusee : pas de reveil » : le protocole veut que l'hôte tire
    PS0/WAKE à la masse et attende que le capteur réponde en abaissant INT, et
    cette réponse n'arrive pas. Les lectures, elles, fonctionnent.
    Plutôt que de conclure par raisonnement, le portage compte désormais ses
    lectures, ses paquets, ses en-têtes vides, ses écritures et ses réveils sans
    réponse ; le pilote compte les événements décodés par grandeur. Un relevé
    toutes les cinq secondes dit où la chaîne s'arrête au lieu de le laisser
    déduire. L'avertissem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
    [imu_bno085.c, sh2_hal_esp32_spi.c]
2026-09-11 Montrer les en-têtes SHTP lus, pour cesser de raisonner à l'aveugle
    Le banc rend 23287 paquets à la pile SHTP en cinq secondes et zéro événement
    capteur, INT restant bas en permanence. C'est la signature d'un paquet que le
    capteur repropose parce qu'on ne le consomme jamais vraiment.
    Deux causes possibles, indiscernables par le raisonnement : on lit du vrai
    SHTP avec une mauvaise longueur, ou on lit de la bouillie qui parse comme une
    longueur plausible. Un en-tête SHTP porte son canal — 0 à 5 — et un numéro de
    séquence : les afficher tranche en un flash.
    Les six premiers paquets, puis un sur dix mille.
    Claude-Session: htt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
    [sh2_hal_esp32_spi.c]
2026-09-11 Lecture SHTP en deux transactions séparées, et non CS maintenu bas
    Le banc rendait 23000 paquets par seconde à la pile et zéro événement. Le
    vidage des en-têtes a tranché : du SHTP parfaitement valide, canal 0, charge
    utile 01 03 03 03 — le rapport de liste d'erreurs du composant, qui
    s'allongeait. Et la séquence ne passait que de 5 à 13 entre le paquet 6 et le
    paquet 10000 : le même paquet relu un millier de fois, jamais consommé.
    La cause est le motif de transfert. Le portage lisait l'en-tête puis le corps
    en gardant CS bas entre les deux. Le composant n'y voit pas une lecture en
    deux temps : il y voit une lecture suivie d'une ÉCRITURE, refuse le paquet
    malformé, empile u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
    [imu_bno085.c, sh2_hal_esp32_spi.c]
2026-09-11 Emettre des zeros sur MOSI pendant les lectures SHTP
    Le SPI est full-duplex : il n'existe pas de transaction de lecture pour
    le BNO08x, seulement des echanges. Ce que le maitre sort sur MOSI pendant
    qu'il rentre un paquet, le composant le lit comme un en-tete SHTP venant
    de l'hote.
    ESP-IDF, quand tx_buffer vaut NULL, ne garnit pas la FIFO d'emission :
    MOSI rejoue le contenu precedent. Le composant voyait donc un paquet
    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
2026-09-11 Reveiller le BNO085 avant d'ecrire, et corriger la mesure d'aller-retour
    Apres le reset, le concentrateur dort (datasheet section 5.2.2) : il
    n'assertera H_INTN que si l'hote le lui demande, en tirant H_WAKEN — la
    broche PS0, repurposee apres le reset — a la masse. Attendre H_INTN sans
    reveiller, c'est attendre une fenetre qui ne s'ouvre que par hasard,
    quand le composant avait de lui-meme quelque chose a dire.
    Ce reveil avait ete retire au commit precedent, a tort. L'explication
    n'est venue qu'apres : tant que le defaut MOSI etait present, le
    composant avait toujours une erreur a signaler, donc H_INTN restait bas
    en permanence, donc le reveil ne servait a rien — et son absence ne se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
    [link_monitor.py, sh2_hal_esp32_spi.c]
2026-09-11 Consigner la latence de liaison mesuree : 1,57 ms aller simple
    Aller-retour median 3,14 ms, max 3,88 ms, sur 100 echantillons a 921600
    bauds, mesure au banc avec tools/link_monitor.py une fois le moniteur
    corrige. La valeur de 1,5 ms qui figurait la etait un ordre de grandeur
    pose faute de mesure ; elle se trouvait juste, ce qui ne la rendait pas
    moins inventee.
    Point 5 de la recette du banc B1.
    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
    [link_bench.yaml]
2026-09-19 Verser les documents de conception de la carte safety_power
    Deux documents produits hors de ce depot et restes non suivis : le
    handoff de saisie du schema safety_power et le plan de conception de la
    feuille P2 « rails d'alimentation ». Ils decrivent l'etat fige au 16
    septembre 2026 et les points GATE qui bloquent la saisie EasyEDA.
    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
2026-09-19 Documenter l'installation, le flash et la verification de bout en bout
    docs/DEMARRAGE.md part d'une machine vierge et s'arrete quand /imu/data
    sort a 100 Hz dans Foxglove. Il manquait : tout ce qui a ete appris au
    banc vivait dans des en-tetes de fichiers source ou dans un historique
    de conversation, ce qui ne se retrouve pas quand on reprend le projet
    trois semaines plus tard, et pas du tout depuis une autre machine.
    Contenu : les trois roles d'outillage et pourquoi on ne les melange pas,
    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
2026-09-20 Etalonner le BNO085 : activation, sauvegarde du DCD, et pilotage au banc
    Le firmware n'appelait jamais sh2_setCalConfig. Le BNO085 sait corriger
    ses biais en fonctionnement — c'est son interet principal face a une
    centrale brute — mais il ne le fait que si on le lui demande, et il ne
    conserve le resultat d'une mise sous tension a l'autre que si c'est ecrit
    en flash. Sans les deux, il sort ses valeurs d'usine.
    Mesure au banc du 20 septembre 2026, trois orientations franches :
    a plat (0,270 ; -0,230 ; -10,152) norme 10,158
    sur un chant (0,382 ; -10,188 ; -0,304) norme 10,200
    sur l'autre (-0,270 ; 9,460 ; -1,266) norme 9,548
    Les normes ne sont pas egales, donc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
    [imu.h, imu_bno085.c, imu_cal.py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]
2026-09-20 Corriger le chemin d'ESP-IDF dans le guide de demarrage
    Le dossier installe s'appelle esp-idf-v5.5, pas esp-idf : la version est
    dans le nom pour que deux versions puissent coexister, ce qui arrive des
    qu'un projet tiers en exige une autre. Le guide donnait
    ~/esp/esp-idf/export.sh, qui echoue silencieusement — le shell ne trouve
    pas le fichier, et l'erreur suivante est un idf.py introuvable, plusieurs
    commandes plus loin.
    Ajoute aussi l'alias recommande par Espressif plutot qu'une ligne dans le
    .zshrc, qui ralentit l'ouverture de chaque terminal.
    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
2026-09-20 Consommer IMU_CAL cote ROS, et alerter quand l'etalonnage n'est pas sauve
    Le commit qui a ajoute IMU_CAL au firmware n'a rien donne au noeud ROS
    pour la lire : la trame arrivait toutes les 100 ms et tombait dans
    unknown_frames. Le hash du protocole, lui, concordait — les deux cotes
    ont bien la meme definition — ce qui montre exactement ce que ce compteur
    attrape et que le hash ne peut pas voir : une trame connue des deux
    cotes mais traitee d'aucun.
    ImuStatus gagne cal_enabled, cal_saves, cal_autosave et cal_last_result.
    Les deux premiers disent des choses differentes et les confondre coute
    une seance de banc : l'un dit que le capteur corrige ses biais EN CE
    MOMENT, l'autre que la correc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
    [bridge_node.cpp]
2026-09-20 Ne pas compter le reset d'initialisation du BNO085 comme un incident
    Le capteur annonce la fin de son initialisation par un evenement
    SH2_RESET, a chaque demarrage, sans exception. Le firmware le comptait
    comme les autres, donc sensor_resets valait 1 en permanence — et le
    diagnostic ROS passe en ERREUR des qu'un reset est signale. L'IMU
    apparaissait donc au rouge des le boot, sur une machine parfaitement
    saine.
    Un voyant toujours rouge ne dit plus rien. C'est pire que pas de voyant :
    le jour ou le capteur se reinitialise vraiment — alimentation instable,
    cablage SPI marginal —, personne ne le remarquera.
    Le drapeau s_running separe la sequence de demarrage du fonctionnement
    normal. P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
    [imu_bno085.c]
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2026-09-20 Ne plus redemarrer l'ESP32 en ouvrant le port serie
    Sur une DevKitC, DTR et RTS ne sont pas decoratifs : ils pilotent EN
    (reset) et IO0 (mode de demarrage) a travers le circuit d'auto-reset du
    montage. Le noyau les assertit a l'ouverture du port et les abaisse a la
    fermeture (HUPCL), et pyserial fait pareil. La carte redemarre donc a
    chaque ouverture — et selon l'ordre des transitions elle peut rester dans
    le bootloader ROM, muette, sans la moindre erreur cote hote.
    C'est ce qu'on observait depuis ce matin, sur trois programmes differents
    et sans jamais le nommer : la liaison marchait apres un rebranchement
    physique, puis plus rien des qu'un second programme rouvrait le port. On
    a mis ca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
    [imu_cal.py, link_monitor.py]
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2026-09-20 Remettre l'ESP32 en mode execution a l'ouverture du port
    Relacher DTR et RTS ne suffisait pas. Une carte deja partie dans le
    bootloader ROM y reste jusqu'a une coupure d'alimentation : elle y
    attend un televersement, a 115200, et reste donc muette pour un hote qui
    lit a 921600 — sans qu'aucune erreur ne soit levee nulle part.
    Le banc l'a montre : apres une impulsion de reset explicite lancee a la
    main, la donnee revenait ; en relancant le noeud sans toucher au cable,
    le diagnostic repassait de « aucune trame recue » a « taux d'erreur
    superieur a 1 % », signature d'octets recus a un debit qui n'est pas le
    bon.
    Le transport execute donc la sequence d'esptool, a l'envers du mode
    telecha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
    [bridge_node.cpp, link_bench.yaml]
2026-09-20 Consigner le piege du bootloader ROM dans le guide de demarrage
    Deux lignes de depannage, parce que ce defaut a coute une demi-journee
    et qu'il ne ressemble a rien de ce qu'on cherche : la carte demarre en
    mode telechargement, attend un televersement a 115200, et reste muette
    pour un hote qui lit a 921600 — sans qu'aucune erreur ne soit levee
    nulle part.
    La deuxieme ligne note que le silence complet et le bruit illisible sont
    deux etats du meme probleme, pas deux pannes differentes. On a perdu du
    temps a les traiter separement.
    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
2026-09-20 Documenter l'etat du banc IMU et ce qu'il reste a faire
    docs/HANDOFF-banc-imu.md existe pour qu'on puisse reprendre ce travail
    dans trois semaines sans relire vingt-cinq commits : ce qui marche et
    avec quels chiffres, ce qui a ete casse et par quel mecanisme, ce qui
    reste et comment le faire.
    La partie qui a de la valeur est la deuxieme. Chacun des defauts trouves
    etait silencieux et aucun ne ressemblait a sa cause : le SPI full-duplex
    ou MOSI rejoue la transaction precedente, le reveil PS0 dont l'absence
    etait masquee par ce premier defaut, l'etalonnage jamais active qui
    donnait un biais de 0,58 m/s2 sans rien signaler, et le bootloader ROM
    ou la carte attend un televersement a 115200 en r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
2026-09-20 Lidar X4 : la configuration qui marche, etablie par la mesure
    Une apres-midi d'hypotheses successives — alimentation, DTR, resolution
    fixe, frequence, intensite — chacune plausible, chacune fausse ou
    confondue avec une autre. Ce qui a fini par marcher : reproduire a
    l'identique tri_test, le programme d'exemple du SDK qui recevait des
    scans, puis s'en ecarter un parametre a la fois.
    Trois ecarts avec la documentation, tous mesures sur l'exemplaire du
    banc (serie 2021090300040777, firmware 1.10) :
    - isSingleChannel true, alors que la table du constructeur dit false
    pour le X4. Cet exemplaire livre ses informations produit comme un
    double canal mais ne delivre ses scans qu'en mono-can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
    [lidar_bench.yaml]
2026-09-20 Lidar : invalid_range_is_inf est sans effet, le compter correctement
    Mesure au banc : avec invalid_range_is_inf a true, les mesures sans echo
    sortent quand meme a 0.0 — 221 zeros sur 667 points, aucun +inf. Le
    reglage promet REP-117 et ne le tient pas.
    Deux consequences ecrites la ou on les cherchera :
    - tout consommateur de /scan doit filtrer sous range_min lui-meme.
    slam_toolbox et Nav2 le font ; un noeud maison qui l'oublierait verrait
    221 obstacles colles au capteur ;
    - le taux de couverture se compte sous range_min, pas par isfinite(),
    qui donne 100 % et ne mesure rien. Le guide avait le mauvais critere.
    Releve du banc : 67 % de couverture, 0,31 a 5,19 m. Au-dessus du seuil
    d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
    [lidar_bench.yaml]
2026-09-20 Documenter les deux bancs : ce qui marche, ce qui a casse, comment lancer
    Trois documents pour trois usages.
    docs/HANDOFF-banc-lidar.md, pendant du handoff IMU : les chiffres du
    banc (667 points par tour, ~7,5 Hz libre, 67 % de couverture, 0,31 a
    5,19 m, orientation validee), les six defauts avec leur mecanisme, et
    ce qui reste — alimentation USB_PWR, diagnostics sur /scan, URDF,
    ignore_array, remplacement en phase 4. La section 2.1 consigne la
    methode qui a debloque la journee, parce qu'elle vaut plus que chaque
    correction prise separement : quand plus rien ne marche, revenir a un
    temoin qui marche et s'en ecarter un parametre a la fois.
    docs/DEMARRAGE.md gagne une fiche de lancement en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
    [lidar_bench.yaml]
2026-09-21 Banc moteurs : nœud MOTION sur un second ESP32, trois ZS-X11H depuis Foxglove
    Protocole : MOTOR_CMD 0x110 (quatre consignes i16 ×0,001, 50 Hz), MOTOR_ENABLE
    0x111 (magic 0xEB), MOTOR_STATE 0x1A0 (appliqué, masque, drapeaux, âge), enum
    motor_flag ; HEARTBEAT_MOTION_FRONT passe en bench. Hash 0x670192A7.
    Firmware esp32_motion : table de quatre moteurs dans board_config.h (PWM 20 kHz
    + RC vers VR, DIR/STOP open-drain), CONFIG_RETRIEVER_MOTOR_COUNT=3 aujourd'hui,
    4 quand m3 est câblé. Tâche 200 Hz, chien de garde 500 ms, pente à
    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
    [bench_motors.json, motors_bench.yaml]
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2026-10-07 feat: bancs moteurs ESP32, protocole, outils et documentation
    [P4-ESP32-header-inventory.csv]
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2026-11-11 docs(pcb): dossier de conception v2 et chaîne d'outils KiCad
    - conception-v2.md : pourquoi la v1 a échoué, principes, ordre de
    fabrication, décisions D1–D9, interfaces communes, défaut de la
    chaîne de frein (5V_BRAKE passe par motor_interface), corrections
    ICD v1.3, erreurs de calcul du filtre Hall, critères de sortie.
    - Un cahier des charges par carte : rôle, connecteurs, composants et
    statut, points à corriger avant schéma, mesures bloquantes, recette.
    - outils.md : KiCad 10 piloté par kicad-cli et pcbnew, Freerouting 2.5
    (Java >= 25), easyeda2kicad, KiBot, KiKit ; emplacements, pièges et
    chaîne validée sur une carte de démonstration.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

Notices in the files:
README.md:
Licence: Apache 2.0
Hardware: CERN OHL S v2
